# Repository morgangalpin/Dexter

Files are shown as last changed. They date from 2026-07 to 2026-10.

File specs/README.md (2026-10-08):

# Dexter — Specification

This directory is the **specification of the Dexter robot arm**: the authoritative design of
record from which all hardware, firmware, gateware, documentation, and build artifacts are derived.
It describes the robot — what it is, what it must do, and how it is built — not the process by which
this information was recovered. Where a design decision has been made, the specification states it as
the design; where a decision is still required to complete the robot, the specification records it as
work remaining (see [Design status](#design-status) and
[009-Design-Completion.md](009-Design-Completion.md)).

## Design identity and versioning

**No document in this set states its own version and revision**
([010 § Design identity](010-Versioning.md#2-design-identity)). The version line, the branch and tag scheme,
and the procedure for deriving the next revision are [010-Versioning.md](010-Versioning.md); the forward
roadmap is [011-Roadmap.md](011-Roadmap.md); the recorded history of each revision is
[CHANGES.md](../CHANGES.md) in the repository root.

## Specification map

Read top to bottom for a full picture; each document is self-contained and cross-links the others.

| # | Document | Scope |
|---|---|---|
| — | [README.md](README.md) | This map, document ownership, the design-status scheme, and the specs workflow |
| 001 | [Overview](001-Overview.md) | What Dexter is; system decomposition; how the specification is organized |
| 002 | [Requirements](002-Requirements.md) | Capabilities the robot must deliver: degrees of freedom, workspace, precision, motion limits, environment, interfaces |
| 003 | [Kinematics](003-Kinematics.md) | Coordinate frames, joint conventions, link lengths, the Denavit–Hartenberg model, and motion commands |
| 004 | [Mechanical Architecture](004-Mechanical-Architecture.md) | Joint-by-joint mechanical design: drivetrains, structure, and the design intent behind each subassembly |
| 005 | [Electronics and Control](005-Electronics-and-Control.md) | Sensing, actuation, the FPGA joint-servo loop, boards, power, and the control-command interface |
| 006 | [Firmware and Calibration](006-Firmware-and-Calibration.md) | Firmware parameters, the calibration model, and the factory calibration and bring-up procedure |
| 007 | [Bill of Materials](007-Bill-of-Materials.md) | The parts that realize the design in 004–006, organized by subassembly |
| 007.1 | [Parts Catalog and Sourcing](007.1-Parts-Catalog.md) | Every purchased and fabricated part, de-duplicated across the whole robot, with product specifications and supplier links |
| 007.2 | [3D Printed Parts](007.2-Printed-Parts.md) | Every printed part, de-duplicated, with print quantities and model-file sources |
| 008 | [Assembly](008-Assembly.md) | The procedure that builds the parts in 007 into the robot in 004 |
| 009 | [Design Completion](009-Design-Completion.md) | Design status: the open design decisions that must be closed to make the current design fully buildable |
| 009.1 | [Performance Characterization Protocol](009.1-Performance-Characterization-Protocol.md) | The first-build measurement protocol behind DC-9: test-by-test procedure, required instruments, and the recording template |
| 009.2 | [Test Build Manifest](009.2-Test-Build-Manifest.md) | What the first measurable build contains, the stages it is assembled in, and which open item each stage answers |
| 009.3 | [Render Program](009.3-Render-Program.md) | The single program that renders and verifies the printed-part meshes: its command line, the per-group `render.json` schema, and the parallel scheduling rules |
| 010 | [Versioning](010-Versioning.md) | Version lineage, design identity, the git branch and tag model for versions and revisions, and the procedure for deriving the next one |
| 011 | [Roadmap](011-Roadmap.md) | Improvements anticipated beyond the current revision |
| — | [CHANGES.md](../CHANGES.md) | The design history: what changed in each revision and why (repository root) |

Documents 002–005 specify the robot (requirements → kinematics → mechanics → electronics/control).
Documents 006–008 are **derived artifacts**: firmware configuration, the parts list, and the build
procedure all follow from the design in 002–005 and must be regenerated when it changes. 007.1 and 007.2
are derived one step further — from 007 — and each carries its own regeneration procedure. Document 009
is the live list of decisions still owed on the current revision; document 010 governs how the whole set evolves,
and 011 is what is intended beyond the current revision.

## Document ownership

Each document is the **single source of truth** for one set of information. Where another document needs
that information it links to the owner rather than restating it: a value written down twice will eventually
disagree with itself, and there is then no way to tell which copy is the design. When adding to the
specification, find the owner below and write it there.

| Information | Owner |
|---|---|
| What the robot must do: requirement IDs, targets, and their traceability | [002](002-Requirements.md) |
| Frames, joint conventions, link lengths, the DH model, and motion commands | [003](003-Kinematics.md) |
| Mechanical design and design intent, subassembly by subassembly; drive ratios and mechanical interfaces | [004](004-Mechanical-Architecture.md) |
| Sensing, actuation, boards, power, the control loop, and the command interface | [005](005-Electronics-and-Control.md) |
| Firmware parameter values, drive constants, and the calibration and bring-up procedure | [006](006-Firmware-and-Calibration.md) |
| Which parts each subassembly consumes, and in what quantity | [007](007-Bill-of-Materials.md) |
| Part identity, specification, supplier, price, and lead time | [007.1](007.1-Parts-Catalog.md) |
| Print quantities and model-file sources for printed parts | [007.2](007.2-Printed-Parts.md) |
| The order of operations that builds the robot | [008](008-Assembly.md) |
| **Design status** — what is still open, its priority, and its definition of done | [009](009-Design-Completion.md) |
| How a first build is measured, and what each measurement closes | [009.1](009.1-Performance-Characterization-Protocol.md) |
| The mesh render and verification program: command line, `render.json` schema, and scheduling rules | [009.3](009.3-Render-Program.md) |
| Version and revision identity, and the procedure for deriving the next one | [010](010-Versioning.md) |
| Work anticipated beyond the current revision | [011](011-Roadmap.md) |
| What changed in each revision, and why | [CHANGES.md](../CHANGES.md) |

Part geometry is owned by the model sources rather than by this set: a dimension a `.scad` file computes is
stated there, and referenced here.

**[`check-specs.rs`](check-specs.rs) enforces this.** It fails when a run of prose is restated across two
documents, when a document outside 009 labels its own design status, and when a cross-document link or
heading anchor does not resolve. Run it from the repository root before committing a change to the
specification:

```
./specs/check-specs.rs
```

An overlap that is genuinely not a second source of truth — a shared part number, a stock sentence opener
— goes in `specs/.duplication-allow` with a phrase from it. Suppressing a finding is a decision to be
made deliberately and rarely; the first question is always which document owns the information.

## Design status

Status is design maturity, and — like every other kind of information here — it has exactly one owner:
[009-Design-Completion.md](009-Design-Completion.md). **Every other document states the design as the
design of record and does not label its own maturity.** Where a passage depends on something still open, it
links to the item in 009 that owns it instead of repeating that item's state.

So read the set this way: **anything not named in 009 is `[Specified]`** — defined and traceable to
validated evidence (a physical unit, factory calibration data, released firmware, or a CAD model), and safe
to build to. What 009 lists is what is not yet that:

- **`[Provisional]`** — The design is defined by this specification and is the current design of record,
  but has not yet been validated on a physical build. It may change once verified. Treat it as a
  first-issue engineering design: buildable, but confirm before committing irreversible work
  (cutting carbon fiber, ordering long-lead parts).
- **`[TBD]`** — A design decision required to complete the current design has not yet been made. `[TBD]`
  items block a complete build.

The markers describe the **maturity of the design**, not the confidence of an observer. Each item cites its
**source of record** (a file, CAD assembly, factory document, or measurement) so the design remains
traceable. Provenance is traceability metadata, not the organizing narrative of the specification.

---

# Specs Directory (workflow)

Specification files are the source of truth. All code, documentation, and artifacts are derived from specs.
Project specification files are contained in the `specs/` directory in the project root.
Finer-grained feature spec files are contained in a `specs/` directory in a feature's subdirectory.

## File Naming
- `<number>-<descriptive-name>.md` where number is a 3-digit prefix (001, 002) and name is kebab-case.
- Use decimal notation for related specs (001-Overview.md, 001.1-Architecture.md, 001.2-Stack.md).

## Workflow
1. Find the owning document ([Document ownership](#document-ownership)) and update it there.
2. Generate/update code, tests, documentation, and build artifacts from the spec.
3. Verify the artifacts match the spec and that tests validate the requirements.
4. Run `./specs/check-specs.rs` and resolve anything it reports.

For this hardware project the "artifacts" derived from the spec are the firmware configuration
([006](006-Firmware-and-Calibration.md)), the bill of materials ([007](007-Bill-of-Materials.md)), the
assembly procedure ([008](008-Assembly.md)), and the CAD/build files they reference — not application code.
When the design in 002–005 changes, regenerate those derived documents to match.

## Diagrams
- Use Mermaid for all diagrams.
- May be inlined as mermaid code blocks.

## Documentation Standards
- Update spec files during design and build with details, clarifications, and behavioral requirements discovered.
- Record architectural decisions in `specs/*.md` for consistency across revisions.
- Correct grammar and punctuation are required in all documentation and comments.
- Use neutral statements describing the robot ("The base is bolted to a rigid surface"), not the author's process.

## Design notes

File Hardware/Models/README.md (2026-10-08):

# Models

Model files for the robot's printed parts, organized by **arm component**. This directory is the build
source: everything needed to print one complete robot is here, and nothing else is. Most parts are meshes
you can print directly; `700-Differential/` is parametric `.scad` and is rendered first, as is the base
mounting plate — see [Moving to OpenSCAD](#moving-to-openscad).

- **[robot_assembly.scad](robot_assembly.scad)** — the arm composed in the CAD kinematic frame, so the
  build can be reviewed by looking at it. Every placement in it is solved from a feature the part carries;
  a part whose position nothing fixes is listed in that file's `UNPLACED` rather than drawn somewhere
  plausible, which is what lets a missing part show as a hole. `700-Differential/diff_assembly.scad` is the
  same idea one level down, and this file composes it in by its `diff_centre()`. A mating feature outranks
  a bounding box there: the differential is oriented by the L3 spigot Diff Body A carries and by the side
  its End Pulley faces, and where the measured cover bodies disagree with that the file reports the
  disagreement rather than moving the part into them.
- **[print_fit.scad](print_fit.scad)** — the two print-fit clearances every part's `config="revised"`
  draws its fits with, press and slip, and the running gap kept between parts that turn past each
  other. Tune the two fits on
  [`950-Tooling/fit_coupon.scad`](950-Tooling/fit_coupon.scad); the policy is
  [007.2 § Print fits](../../specs/007.2-Printed-Parts.md#print-fits).
- **[PART-INDEX.md](PART-INDEX.md)** — every part in
  [007.2](../../specs/007.2-Printed-Parts.md#printed-parts) with its file, grouped as the directories are.
- **[MANIFEST.csv](MANIFEST.csv)** — every model and model-source file (meshes, CAD, `.scad`, and the
  script that renders and verifies them) with its size, SHA-256, and, for STLs, format and triangle count.
  Sizes and hashes are of the **repository** bytes, so text files are counted with LF line endings — on a
  Windows checkout (`core.autocrlf=true`) the working-tree file is larger than its row says. Compare a
  text file by normalizing CRLF to LF first; binary files compare directly. The text set is `.step`
  (ISO-10303-21 is ASCII), `.scad`, `.rs`, `.json` and `.md`; `.stl`, `.f3d`, `.ipt`, `.dwg`, `.skp`
  and `.skb` compare directly. The group column is the file's directory; a file that belongs to no one
  component group is grouped `(all)`.

## Layout

Directories follow the `PBS` component groups in [007.2](../../specs/007.2-Printed-Parts.md#printed-parts).
Files are named `<PBS>_<PartName>.<ext>`, so a part number alone locates its file, and the directory
listing sorts in build order.

`PBS #` is the **authoritative part number** — the only scheme that names every part, and the one
[007](../../specs/007-Bill-of-Materials.md), [007.1](../../specs/007.1-Parts-Catalog.md),
[007.2](../../specs/007.2-Printed-Parts.md) and [008](../../specs/008-Assembly.md) all key on. The `HDI-`
and `TI1-` CAD IDs name bodies in the CAD model and cover only 13 of 70 parts; the `KP`/`KA` numbers in
[`Reference/onshape-v1/`](Reference/onshape-v1/README.md) belong to the superseded v1 design. See
[007.2 § Part identifiers](../../specs/007.2-Printed-Parts.md#part-identifiers).

| Directory | Parts | Files | What |
|---|---|---|---|
| [`100-Base/`](100-Base/) | 7 | 9 | Base clamp, mount, mounting plate, stator holder, code disc; the Stator Holder is `.scad` |
| [`200-ArmBody/`](200-ArmBody/) | 9 | 9 | Arm body, stator holder and balancers, belt directors; the Stator Holder is `.scad` |
| [`300-Pivot/`](300-Pivot/) | 4 | 4 | Main pivot, code disk, motor end caps |
| [`400-EndArm/`](400-EndArm/) | 10 | 12 | Axis intersection, hub, internal and external pulleys; the External pulleys are `.scad` |
| [`500-ExternalGear/`](500-ExternalGear/) | 7 | 9 | External gear, stator holder, mount and nut holders; the Motor End Cap and Stator Holder are `.scad`; `exgear_assembly.scad` places the group with its motor and drive, and closes J3's stack |
| [`600-StrainWave/`](600-StrainWave/) | 3 | 5 | Wave gen coupler, flex spline attach and cap; the Attach and Cap are `.scad`, and `c201_spline_seat.scad` holds the drive's interface for them and the three Stator Holders |
| [`700-Differential/`](700-Differential/) | 10 | 17 | Split gears, diff gear shaft and axle, diff pulleys, diff bodies — **the OpenSCAD set**, `.scad` only; the meshes it is measured against are under `Reference/meshes/`; `diff_assembly.scad` places the set and has a section view |
| [`800-Harness/`](800-Harness/) | 14 | 17 | Wire entries, pivot plugs, PCB brackets, strain reliefs, photointerrupter shrouds |
| [`900-ToolInterface/`](900-ToolInterface/) | 8 | 27 | Tool interface body, roll, span, gripper — **the parametric set** |
| [`950-Tooling/`](950-Tooling/) | 2 | 12 | Solder jigs, glue-rig jig bodies, and the print-fit coupon |
| [`Reference/`](#reference) | — | 226 | Not printed for a build. See below |

### Shared parts

Sharing happens at **subassembly** level, not file level, so no part lives in two directories:

- **`600-StrainWave/`** is three parts at quantity 3 — one adapter set per strain-wave joint (base, pivot,
  end arm). It is a component in its own right rather than a member of any one joint.
- **`800-Harness/`** parts are distributed throughout the robot (strain reliefs at quantity 10, PCB spacers
  at 4).

Only two *files* serve more than one part number, and both stay inside one component. See
[PART-INDEX](PART-INDEX.md#one-geometry-two-part-numbers).

### Reference

Not part of a build. Kept because the geometry exists nowhere else.

| Directory | Files | What |
|---|---|---|
| `Reference/onshape-v1/` | 193 | **v1** B-rep solids as STEP, plus assembly definitions. Dimension recovery only — see [its README](Reference/onshape-v1/README.md) |
| `Reference/inventor/` | 8 | Inventor `.ipt` with feature history: arm, CF tube and tube mould, valve and ratchet, arm-body spacer. No part in the build list maps to these |
| `Reference/covers/` | 6 | Cosmetic ducts, **not in the [007](../../specs/007-Bill-of-Materials.md) build list**. Includes SketchUp source |
| [`Reference/meshes/`](Reference/meshes/) | 17 | The original meshes of parts that now have parametric source: `700-Differential/`, `400-EndArm/`'s two External pulleys, `500-ExternalGear/`'s Motor End Cap, `600-StrainWave/`'s Flex Spline Attach and Cap, and the three Stator Holders in `100-Base/`, `200-ArmBody/` and `500-ExternalGear/`. A part's mesh moves here when its `.scad` lands; `render.rs --verify` measures its renders against these meshes (see [Checking a group](#checking-a-group)), and each External pulley `.scad` builds on its own |
| [`Reference/superseded/`](Reference/superseded/) | 2 | Earlier revisions of parts the build no longer uses. `GlueRig_EndArmHubToDiff_B_span309500.stl` is the L3 rig as first exported ([PART-INDEX](PART-INDEX.md#glue-rig-jigs)). `DiffA2CodeDiskEndStop.dwg` is the v1 J4 code disk and end stop, whose 115-slot track is now cut into `#730-002`'s rim |

## Known defects

**A tangency, corrected in place.** `400-EndArm/420-001_EndArmHub.stl` was not a closed 2-manifold. The
part carries four Ø3.000 holes whose centres sit on a Ø30.500 circle, each tangent to the Ø27.500 bore
exactly — 15.250 − 1.500 = 13.750 — and the tessellator honoured the tangency by giving both surfaces a
vertex at the same coordinate. At three of the four, (0, 13.750), (0, −13.750) and (13.750, 0) in the
part's own frame, they then shared the whole line from z = −2.000 to z = −30.000: four faces on one edge
instead of two, and two cones of faces meeting at the single vertex at the z = −2.000 end, with no way to
say which faces bound the material. The fourth, at (−13.750, 0), is cut into different segments on each
surface, shares no edge, and is manifold — which is why there were three and not four. CGAL takes none of
it, so a render of anything holding this part stopped at `The given mesh is not closed`.

It was not a hole — the mesh has no boundary loop anywhere, which is why `scadmesh repair` reported it as
not closed and then found nothing to fill — so what it needed was each contact opened rather than patched:

```
scadmesh pinch 400-EndArm/420-001_EndArmHub.stl --out 400-EndArm/420-001_EndArmHub.stl
```

That gives one surface at each contact its own vertex 1 µm off the line, along its own normal, which grows
the material between the two surfaces by that much: 6 triangles added, no existing vertex moved, the
bounding box unchanged and the volume 0.028 mm³ — four parts in ten million — larger. The file also holds
a second closed shell that shares no edge with the body, the 18 × 20 × 20 mm block on the spigot axis at
x 26.500..44.500, y ±10.000, z −35.000..−15.000, so this is a multi-body export rather than one unioned
solid. That is not a defect: two shells convert as readily as one.

**A second tangency, corrected the same way.** `500-ExternalGear/510-001_ExternalGear.stl` failed the same
way. Two of its surfaces shared 91 edges on one ring in the part's frame, at x 21.215 and r ≈ 33.7, so
`scadmesh repair` found no boundary loop, CGAL refused the mesh, and every boolean on the gear stopped at
`The given mesh is not closed`. It is corrected in place:

```
scadmesh pinch 500-ExternalGear/510-001_ExternalGear.stl --out 500-ExternalGear/510-001_ExternalGear.stl
```

That added 182 triangles, left the bounding box unchanged, and added 0.708 mm³ to the volume (1 part in
10⁵). The gear now intersects with the Mount, the Mount Top and the lower 6810. Two pairs still fail
inside CGAL's boolean (`applyBinaryOperator` asserts) and stay unjudged. The Stator Holder's keys meet
the gear's slots line-to-line, which is why `render.rs --verify` checks that fit by sections.
The upper 6810's assertion persists with its envelope shrunk to Ø64.9, so it is not the seat's Ø65; its
cause is not isolated.

Three files have held the wrong geometry rather than the wrong topology, and all three are corrected in
place:

- `100-Base/110-001_BaseMountBottom.stl` was the **un-bolted predecessor**, an 85 × 85 × 98 mm part whose
  bottom face carried no fastener features whatever: sections through it return only an outer Ø ≈ 72.9
  profile and a Ø53.99 bore, and the six 60°-spaced features on its Ø71.302 circle decompose into six
  straight lines — 12.94 × 3.82 mm slots for the `#110-003` CF strakes, not a bolt pattern. The design of
  record is a **bolted** base ([004 § Base (J1)](../../specs/004-Mechanical-Architecture.md#base-j1)), and
  the CAD model holds it as `BaseMountBottom_Bolted v9`: 150 × 150 × 98 mm, with eight Ø6.000 mounting
  holes through a 10 mm flange. That is now the file, exported from `dde/HDIMeterModel.gltf` in the part's
  own frame. **This was found by re-checking a file the manifest was perfectly happy with** — the previous
  entry was a valid, closed, correctly named mesh of the wrong revision.
- `200-ArmBody/200-001_ArmBody.stl` was not the Arm Body. It held
  `ArmBodyFrontStrakeMED.stl` — a 20-triangle 4.9 × 9.9 × 32 mm block — byte for byte, so the mirror
  had matched the archive's `ArmBody*` prefix rather than the part. The Arm Body is
  `ArmBodyWEncode.stl` in [thing:3781990](https://www.thingiverse.com/thing:3781990) (11,946 triangles,
  99.6 × 108.1 × 98.0 mm), and that is now the file. It is the part: its 29 × 29 mm L2 tube socket sits
  where the CAD model's `HDI-310-001_ArmBody` puts it, to the seat depth
  [C-504](../../specs/007.1-Parts-Catalog.md#c-504--braided-carbon-fibre-square-tube-1) states. **Any prefix-matched file in
  this mirror is worth re-checking the same way** — a file that is the right size and the wrong part
  passes every check the manifest makes.
- `Reference/meshes/700-Differential/710-002_SplitGearBottom.stl` was 1000× out of scale; it is
  dimension-checked against its mates and now also has parametric source
  ([DC-11(f)](../../specs/009-Design-Completion.md#procurement-data)).

The Base Mount Bottom is the only file here taken from the GLTF, and it takes two steps rather than one:

```
scadmesh gltf dde/HDIMeterModel.gltf --node HDI-110-001_BaseMountBottom \
    --frame HDI-110-001_BaseMountBottom --scale 1000 --out raw.stl
scadmesh repair raw.stl --out 100-Base/110-001_BaseMountBottom.stl
```

`--scale 1000` is needed because `--frame` reports the node's own units — metres here — where the default
world export converts to millimetres. And the GLTF mesh arrives with three 11.5 µm holes at the central
bore's seam, so it is not a closed solid until `repair` triangulates them; every other mesh in this
directory is closed, and this one now is too. The repair adds 3 triangles and moves no existing vertex,
leaving surface area and enclosed volume unchanged.

`Reference/meshes/700-Differential/720-002_DiffGearAxle.stl` is the set's only ASCII STL. That is not a
defect — it prints normally — but it is why [MANIFEST.csv](MANIFEST.csv) records it as `ascii-or-nonstd`
with no triangle count.

## Formats, and what can actually be edited

| Format | Where | Editable? |
|---|---|---|
| `.scad` | `700-Differential/` | **Yes** — parametric OpenSCAD source, the intended format going forward (see below) |
| `.stl` | component directories, `Reference/meshes/` | **No.** Mesh only — printable, not meaningfully modifiable |
| `.f3d` | `900-ToolInterface/` | **Yes** — Fusion 360 native, with feature history |
| `.step` | `900-ToolInterface/`, `Reference/onshape-v1/` | **Partly** — B-rep solids. Dimensions can be measured and features cut, but there is no feature tree to drive |
| `.ipt` | `Reference/inventor/` | **Yes** — Inventor native, with feature history |
| `.dwg` | `400-EndArm/`, `900-ToolInterface/`, `Reference/superseded/` | **Partly** — B-rep solids, not 2D profiles as previously recorded here. Each of the three holds one ACIS `3DSOLID` (`421-002` adds six lines and an arc beside it). Reading one needs the [ODA File Converter](https://www.opendesign.com/guestfiles/oda_file_converter); FreeCAD drives it once its path is set, and `ODAFileConverter in/ out/ ACAD2000 DXF 0 1 "*.dwg"` writes the solid as ASCII-encoded SAT in the DXF's group 1 and 3 records |
| `.skp`/`.skb` | `Reference/covers/` | **Yes** — SketchUp source |

**Most of the robot is still mesh-only.** Editable source exists for the differential (`.scad`), the tool
interface (`.f3d`), and the Inventor reference parts. Everything else is a mesh or a dead solid, so
changing one of those parts today means re-deriving it from an STL — the workflow the differential
conversion established (see below). That remaining gap is tracked as
[DC-11](../../specs/009-Design-Completion.md#procurement-data).

## Moving to OpenSCAD

`.scad` is the intended parametric format going forward: it is text, so it diffs and merges in Git, and it
depends on no proprietary tool. Four conventions keep the transition legible:

- **Share the stem.** A rewritten part keeps its mesh's name — `100-001_BaseClamp.scad` for
  `100-001_BaseClamp.stl` — so the two stay findable from each other after they are separated.
- **Treat the STL as output, not source, once a `.scad` exists.** Until then the STL *is* the source of
  record, because for most parts it is the only geometry that exists.
- **Move the mesh to `Reference/meshes/<group>/` when the group is converted**, keeping its stem and
  group directory. It stops being the build source at that point and becomes only what the render is
  gated against, and leaving it in the component directory invites printing the mesh instead of the
  `.scad`. A **converted** part therefore has no `.stl` beside its `.scad`, and which groups have been
  converted is visible from a listing of `Reference/meshes/`. The rule is about a part, not a directory:
  `100-Base/` holds `110-004_BaseMountingPlate.scad` beside six meshes because that part was *authored*
  rather than converted, and the meshes belong to parts nothing has rewritten yet. What a directory must
  never hold is a `.scad` and an `.stl` of the **same** part.
- **Wrap a nested `difference()` in `render()`, not the cut that follows it.** OpenSCAD's *preview*
  normalizes the tree to disjunctive normal form, and `x - (A - B)` rewrites to `(x - A) | (x & B)` —
  one copy of the entire part per term of `A` and of `B`. A subtracted union does not multiply, so an
  array of cuts is rarely the cause even when it is what overflows: it is the nested difference upstream
  that multiplies, and the array merely lands on every copy. Two symptoms follow, and the second is the
  one that gets misread. Past the element cap the normalizer gives up and preview draws an empty tree,
  so a part can export a flawless STL and show nothing. Below the cap it draws, but every primitive is
  redrawn once per product per frame, and the viewport stops turning. `render()` on the nested
  difference collapses it to one mesh, removing the fan-out at its source and costing the export
  nothing. Take the deepest multiplier first: wrapping a downstream cut while a large factor survives
  upstream caps the element count without touching the product count, which cures the empty tree and
  leaves the model exactly as unusable to turn.
  [`730-002_DiffBodyB.scad`](700-Differential/730-002_DiffBodyB.scad) is the worked example — its Ø8
  bore fillet multiplies the whole part, its 115 encoder slots merely land on every copy — and the
  arithmetic and measurements are at that call site. Two things there carry elsewhere. The cheaper
  lever is often not `render()` at all: that fillet's factor is set by how its cutter is built, and
  rebuilding the cutter as a swept polyhedron rather than a chain of hulled spheres took it from 51 to
  7 for nothing. And **measure compile and frame separately** — render the same file at two image
  sizes, because compile does not scale with pixels and a frame does. On that part the variant that
  compiled fastest was the one that could not be orbited, and reading the two costs as a single number
  is what hid it.

**`700-Differential/` is fully converted** (DC-2,
[specs/009](../../specs/009-Design-Completion.md#differential-detail-design)): one `.scad` per part,
shared dimensions in `diff_params.scad`, placements in `diff_assembly.scad`, and `render.json` for `render.rs` to render
both configurations and dimensionally verify each render against its reference STL with `scadmesh`
(from the standalone `openscad-tools` project, checked out beside this repository's parent — bounding
boxes, diameter and face-position bands, cross-sections, tooth counts). Use that directory as the template
for converting the remaining groups.

**Printing the differential therefore takes one command first**: `./render.rs 700-Differential --meshes` writes the
ten meshes to print into `700-Differential/out/revised/`. `out/` is deliberately untracked — a rendered mesh is a build
artifact, and tracking it would leave two copies of the same geometry to disagree. Everything the render
is checked against is under
[`Reference/meshes/700-Differential/`](Reference/meshes/700-Differential/).

`Reference/onshape-v1/parts-step/` is the most useful starting material: STEP solids can be measured for
real dimensions, which an STL cannot give you reliably.

### Verifying a recreated part against its reference

A recreated part is gated on **surface distance**, not on dimensions. `scadmesh compare` asks whether
every reference diameter and face position reappears somewhere in the candidate — a set of
one-dimensional histograms that a wrong body can satisfy in full: a missing boss, a square hole where the
reference has a round one, and a dished flank where the reference bulges all leave the histograms intact.
It once reported ±0.006–0.131 mm agreement on parts deviating by up to 3.8 mm. **A dimensional check is
not a shape check**, and no tightening of its tolerance makes it one. `compare` is retained only to name
*which* dimension moved once `dist` has failed a part; it gates nothing.

The contract every part in `700-Differential/` is held to:

- **`scadmesh dist` within ±0.15 mm in both directions.** Both are required, not a formality:
  candidate→reference finds material the model invented, reference→candidate finds material it never
  reproduced, and a model that is a strict subset of its reference passes the first alone.
- **Build the body from its measured meridional profile** (`scadmesh profile`) rather than from inferred
  diameters and face heights, so flank curvature is reproduced instead of guessed.
- **Preview (F5) as well as render (F6)**, checked rather than assumed — preview fails independently of
  rendering, so exporting an STL and measuring it will pass a part that shows nothing in the GUI. Run
  `openscad --preview -o check.png <part>.scad` and require zero warnings. The failure mode is specific:
  **no cutter may be a module that is internally boolean** — BOSL2's `pie_slice()` and anything taking
  `rounding=`/`chamfer=` are — because `A - (B - C)` normalizes to `(A - B) | (A & C)` and each one
  doubles the preview tree. Build cutters from single primitives, and cut each solid before unioning it
  into an array rather than after.
- **A shared face is not a join.** Where a feature is trimmed to the surface of the blank it stands on,
  CGAL returns the two as separate solids, the blank's face survives the union underneath the feature,
  and the export carries interior surface — which `dist` then measures against nothing, reading over a
  millimetre out on geometry that is dimensionally correct. Trim such a feature to a surface **offset
  into** the blank (`BEVEL_ROOT_UNDER` offsets 0.35 mm) and let the overlap be buried. The `Volumes:`
  line of the render log is the cheap check: a part modelled as one solid must report 2.

**The references are CAD assembly exports (`STLB ASM` headers) and they mislead in three ways.** Run
`scadmesh segment` on a reference before measuring it.

- *Zero-thickness internal shells.* `profile` shows these as doubled-back slivers, one measuring
  0.003 mm across in `710-002`. A clean model must not reproduce them.
- *Unmerged solids.* `710-002` is two bodies — a turned body and a tooth crown, tessellated at 3.85 and
  6.91 triangles/mm² and never merged. Its file volume **double-counts** the ≈352 mm³ where they
  interpenetrate, so a faithful model reads 4.8 % light against the file and correct against the merged
  7001 mm³; volume against an unmerged file is a screening signal, not a verdict. And reference→candidate
  `dist` flags every **buried** surface, because a merged model has no counterpart for them — on this
  part 28 % of reference samples at up to 2.25 mm, none of it a defect. Only candidate→reference gates a
  part whose reference is an assembly export.
- *Stray shells.* `730-002`'s export carries six 1.05 × 1.0 × 1.0 inverted shells (−0.815 mm³ apiece)
  beside the body, and `dist` against the whole file scores them at **0.991 mm**. Against the isolated
  body the same comparison reads **0.332 mm**. Every figure quoted for that part is against body 0, and a
  measurement that skips `segment` reads a part three times worse than it is.

Not every oddity in a reference is an artifact. `720-001`'s apparent degenerate Ø15.5 internal shell is
**twelve Ø0.2 through-holes** on a Ø15.5 circle, 30° apart with one on +x, running the full 60.6 mm of the
part: every triangle around a hole has its normal on that hole's own axis, `segment` returns one closed
body, and the lateral area over any span is π·0.2·span to three decimals. The model reproduces them behind
a `wall_holes` flag. They are **not buildable** — Ø0.2 × 60.6 mm is 303:1, past drilling and far past
printing — so the flag defaults off and the built shaft is solid
([007.2](../../specs/007.2-Printed-Parts.md#differential--0076)).

Two exceptions are enumerated explicitly rather than absorbed into a widened tolerance. The **GT2 pulley**
teeth are cut with a modelled groove profile rather than measured. The **Diff Gear Shaft's tooth form** is
deliberately cut to the shared crown rather than to its own superseded reference
([CR-3A7](../../CHANGES.md)), so its `dist` fails ±0.15 mm in the tooth zone by design; its tooth count
(20, exact), its clocking (within 0.3° of the reference) and every dimension outside the tooth zone are
gated as usual, measured on the render itself. There is **no tooth-band exemption for the bevels** — the
crown is measured (`diff_bevel.scad`) and meets the ordinary surface check with room to spare.

### Checking a group

Every group with `.scad` parts carries a `render.json`, and `./render.rs <group> --verify` (run from this
directory; `all` takes every group) checks it. It renders the group's parts into the group's untracked
`out/`, gates each faithful render against its mesh under `Reference/meshes/<group>/` by the contract above,
checks the revised geometry by probing material and void either side of the faces it moved, and ends in
`ALL CHECKS PASSED` or a failure count. The work runs in parallel; the schema, the check kinds and the
scheduling rules are owned by [`specs/009.3-Render-Program.md`](../../specs/009.3-Render-Program.md).

The machinery is shared, not copied: the [`render-check/`](render-check/) crate, which `render.rs` takes
as a path dependency, finds OpenSCAD and `scadmesh` (`$OPENSCAD` and `$SCADMESH` first), runs a render and
fails it on any warning, a result CGAL reports as not simple, or an empty one, runs the `dist` gate, probes points, and reads
echoes. A group's `render.json` holds only its own gates and checks. Three rules keep the groups from drifting apart:

- **A number a check needs comes from the part.** A `.scad` echoes it at top level as
  `echo(name = value)`, and the check reads that line; the value is never retyped into `render.json`.
- **A group that uses another group's part waits on that group's jobs** rather than repeating its gates.
  `500-ExternalGear/render.json` waits on `600-StrainWave/*` for face-630-005-j3, because J3's stack
  depends on the Flex Spline Attach.
- **A group states its parts once**, in the `parts` of its `render.json`.
  `render.rs --meshes` builds the mesh cache from the same list the checks verify, so an edited part
  reaches the assembly view and the gates alike.
- **`render.rs` is cached by rust-script.** An edit to `render-check/` does not rebuild it. After changing
  the crate, run `rust-script --force render.rs ...` once, then `rust-script render.rs ...`; running
  `./render.rs` directly can use an older build. `700-Differential --verify` takes about 34 minutes.

Two checks are shared across groups. The `seat` kind probes a Stator Holder's revised seat against C-201's
hole pattern as [007.1](../../specs/007.1-Parts-Catalog.md#c-201--521-strain-wave-component-set) states
it, rather than as the seat library cuts it, so the probes test the library. The `clash` kind renders an
assembly's pair. It passes when the intersection is empty or has no volume (a seat, where two
parts share a face), and fails when CGAL cannot intersect the pair at all, because a failed boolean
returns one of its operands.

### Measured state of the differential set

`scadmesh dist`, two-sided sampled surface distance against each reference, in mm. All nine parts render
as one clean solid from measured geometry.

| Part | Worst deviation | Volume vs reference | State |
|---|---|---|---|
| 710-001 Split Gear Top | 0.045 | −0.1 % | faithful (p95 0.010) |
| 710-002 Split Gear Bottom | 0.150 | +0.02 % | faithful (p95 0.050) |
| 710-003 Diff Keeper | 0.023 | −0.8 % | faithful |
| 710-004 Rotate Code Disk | 0.350 | −1.4 % | faithful (p95 0.011; one localized edge) |
| 720-001 Diff Gear Shaft | 0.568 / 0.456 | −2.05 % | cut to the shared crown — fails ±0.15 mm by design |
| 720-002 Diff Gear Axle | 0.094 | −0.02 % | faithful (p95 0.028) |
| 720-003 Diff End Pulley | 0.030 | −0.02 % | faithful |
| 730-001 Diff Body A | 0.016 | — | faithful, 0.000 % of samples over tolerance |
| 730-002 Diff Body B | 0.377 / 0.332 | −0.05 % | **not yet gated** — see below |

`710-002`'s 0.150 mm is a defect in the reference, not the model: circle fits at z 6.3–6.9 centre the
Ø8.5 bore and its funnel on (−0.039, 0.138), **0.143 mm off the axis**, while every turned surface around
them fits the axis to 0.001 mm. It is a clearance hole for wire, so the model keeps it concentric, and
that eccentricity is the whole of the part's excursion past tolerance (0.011 % of samples).

`730-002` is absent from `DIST_GATES`. p95 is inside tolerance in both directions (0.136); it is the
maxima that fail, and both are the same feature on opposite y flats — the chimney base's straight sides
meeting the chimney cone, filleted on the reference at radius ≈1.5 and modelled here as sharp
intersections, 0.377 mm at (32.686, −9.406, 31.057) and 0.332 mm at (32.346, −32.469, 30.915). Filleting
those four junctions is the remaining work, tracked as
[DC-2](../../specs/009-Design-Completion.md#differential-detail-design). Its measured geometry — the
profiles are the dimension tables — is recorded in
[`730-002_DiffBodyB.scad`](700-Differential/730-002_DiffBodyB.scad).

### What the rebuild established

Four findings generalise beyond the differential and are worth applying to the remaining groups.

- **Revolved bodies recover as cones.** Every crown surface on `710-001`, `710-002` and `720-002` is a
  cone, and fitting measured radius against height recovers each one exactly — the four fitted on
  `720-002` leave a maximum residual of 0.0003 mm over six heights. Cone intersections then define every
  edge outright, so no corner coordinate is measured twice.
- **Straight bevel teeth are ruled through the gear apex**, so *one* section reproduces the whole tooth:
  scaling it about the axis by the ratio of heights **is** the surface between them, which
  `linear_extrude(scale=)` draws exactly and without facets. Nothing needs a loft through stacked
  sections. Let the revolved envelope supply the tip, root and end faces, leaving the section responsible
  for the flanks alone. The apex is measured rather than assumed — scaling a section at one height onto a
  measured section at another and minimising the mismatch locates it to ±0.02 mm.
- **A bevel flank is a cubic.** Fitted to 253 measured points (the median over 9 heights × 20 teeth,
  which agree among themselves to 0.002 mm), a single cubic Bézier holds them to **0.006 mm max, 0.003
  RMS** — where the polyline it replaced needed several hundred coordinates per part and still rendered
  as visible facets. Rebuilding this way took `710-001` from 0.225 mm to 0.045 mm, made its bounding box
  exact, cut its triangle count by 56 %, and carried the tooth's concave root fillet as measured, which a
  loft through convex hulls cuts the corner across.
- **Author a shared feature once.** The Split Gear and the Diff Gear Axle are not two similar gears but
  one 20-tooth crown placed twice: sections taken 15.4484 mm apart return outlines **0.0001 mm apart over
  4088 points**, already clocked alike, and `710-002` supplies exactly the material inside the parting
  cone that `710-001` lacks — its area agreeing with `720-002`'s whole tooth ring to 0.007 mm² in 858.
  The gear is defined once in `diff_bevel.scad` and each part intersects it with its own envelope, so
  they cannot drift out of mesh in edit.

### What assembling the set showed

Per-part gating cannot see fit: a part can match its own reference to a hundredth of a millimetre and
still not fit its neighbours. `diff_assembly.scad` places every part by a feature it carries rather than
by a typed offset, and records each finding at the call site that exposes it.

- **The three bevels mesh**, checked rather than asserted: the CGAL intersection of the Split Gear
  against the Diff Gear Axle, and against the Diff Gear Shaft, is **empty in both cases** — as is the
  intersection of whole 20T crowns substituted for both side bevels, whose tips are longer than the
  shaft's cut ones and so is the stronger result. A bevel set meshes exactly when its apexes coincide,
  and each part states where its apex sits on its own axis, so placing the parts by those three numbers
  is the whole of the gear train.
- **The Split Gear's halves need no relative transform.** `710-001` and `710-002` are authored in the
  same frame, and their intersection is a set of open shells enclosing **exactly 0.000 mm³ apiece**
  (`scadmesh segment`), bounded by the seating face at z = 4.000 and by `BEVEL_SPLIT_ROOT` — both
  construction points rather than accidents. An earlier assembly mirrored one half against the other,
  which cannot be right: mirrored about the shared apex the two crowns do not overlap anywhere.
- **The brad holes disagreed by 0.5 mm.** `710-001`'s hole runs z 11.534–12.943 and `710-002`'s
  z 12.089–13.456 — about 1.0 mm of common opening for a Ø1.5 hole taking a Ø1.8 interference-fit brad.
  Neither half can move to fix it, so this is a disagreement between the two references. `config="previous"`
  keeps each reference's own value; `config="revised"` drills both at **z = 12.750**, stated once as
  `BRAD_Z` in `diff_params.scad`. That height is the one both parts have material for (it leaves a full
  millimetre of `710-002`'s Ø27 wall below the hole, where 12.250 would leave 0.500 mm) and it is the
  blind, glued half's own value — the hole that actually holds the brad. Verified by intersecting a
  Ø1.45 probe on that axis with both halves as they sit: **empty in `revised`, not empty in `previous`**.
  The assembly draws the four brads only when both halves drill to one line, so the previous config still
  shows the disagreement by leaving them out.
- **Four stack-ups are kept as measurements in `config="previous"`, and `config="revised"` designs them
  out.** The Diff Gear Axle's boss reaches into the shaft's front MR128 seat, and Diff Body B overlaps the
  toes of all three bevel crowns that turn in it. `revised` seats the boss on that bearing and keeps Body B
  the running clearance off each crown's swept teeth. The figures and constructions are in
  [`diff_assembly.scad`](700-Differential/diff_assembly.scad)'s header and `730-002`'s TOE CLEARANCE.

## Viewing an assembly

An assembly `.scad` can be turned into a section viewer page, an orthographic model cut on a movable
plane with its parts listed, grouped and labelled, by `scadmesh view` from `openscad-tools`. The
assembly must be **viewable**:

- A top-level `part` variable selects what it draws: `"all"`, or one part's id, drawn in its assembled
  position.
- Every value the page quotes is echoed at top level as `echo(name = value)`.

A sidecar `<assembly>.view.json` beside it names the parts, colours and groups, the labels and camera
presets, and the notes. It restates no dimension: part heights come from the exported meshes, and text
quotes echoes through `{name}` placeholders. The format is in `openscad-tools`'
`specs/003-CLI.md` § The view sidecar. Every `*.view.json` in this tree names a viewable assembly.

### Prerequisites

- **OpenSCAD**, found as `openscad-tools`' `specs/003-CLI.md` states for `view`.
- **`scadmesh`** on `PATH`, built from `openscad-tools` (its README § Build); `cargo install --path .`
  in that checkout installs it.
- **`miniserve`**: `cargo install miniserve`.

### Building, serving and opening a view

Run from the directory that holds the assembly — `500-ExternalGear/` for the External Gear stack:

```
scadmesh view exgear_assembly.view.json --out out/view
miniserve out/view
```

and `700-Differential/` for the wrist differential, whose assembly imports the mesh cache that
`render.rs --meshes` builds, so the cache is built first:

```
./render.rs 700-Differential --meshes
scadmesh view diff_assembly.view.json --out out/view
miniserve out/view
```

Then open `http://localhost:8080/index.html`.

- `scadmesh view` writes `out/view/index.html` and one `out/view/parts/<id>.json` per part. OpenSCAD
  exports each part in its own run, one after another, so the build takes the sum of the parts'
  renders — about eight minutes for the External Gear stack. The page is output, like any render, and
  `out/` is untracked.
- The page loads its parts over HTTP, so it must be served; opened from disk (`file://`) it draws no
  parts.
- A rebuild while `miniserve` runs needs only a browser refresh. `Ctrl+C` stops the server, and
  `miniserve -p <port> out/view` serves on another port when 8080 is taken.

### Making an assembly viewable

1. **Write the assembly.** A group's assembly is `<group>/<short>_assembly.scad`; the arm's is
   [`robot_assembly.scad`](robot_assembly.scad). Place every part by a feature it carries, as the
   arm's assembly does. Copy the viewable shape from
   [`exgear_assembly.scad`](500-ExternalGear/exgear_assembly.scad): the `part` variable, a `PARTS` list
   of ids, one module per part, a `draw(p)` that dispatches on the id, and an `assembly()` that draws
   every id `part` selects. Echo every value the page will quote.
2. **Check one part exports alone** — `openscad -D 'part="<id>"' -o check.stl <assembly>.scad` — with
   no warnings.
3. **Write the sidecar**, `<assembly>.view.json` beside the assembly, to the format above;
   [`exgear_assembly.view.json`](500-ExternalGear/exgear_assembly.view.json) is the worked example.
   Every part `id` is an entry of `PARTS`, and every number the page shows is a `{name}` placeholder
   for an echo, never typed.
4. **Build and open it** as above. `scadmesh view` rejects an unknown field, a duplicate id, or a
   label, preset, overlap or focus that names no part or preset before it exports anything, so a
   sidecar mistake fails in seconds.

## What was removed

This directory previously mirrored 909 files (571 MB) organized by where they were downloaded from. That
was reduced to the parts a build needs. Removed:

| Removed | Files | MB | Why |
|---|---|---|---|
| Dropbox in-work variants | 281 | 202.8 | Experimental sweeps (`SplitGearRIN5ccw`, `ExternalGearBelt*`) of parts already covered. `PivotSkirt` was the only unique build part and was kept |
| `.x3g` toolpaths | 14 | 104.7 | Makerbot machine code — not geometry, and not for any current printer |
| v1 legacy STL set | 68 | 56.4 | Superseded by the HD sets |
| Parasolid `.x_t` | 140 | 54.3 | **Byte-for-byte the same solids as the STEP files**, in a proprietary kernel format |
| HD set superseded by HD update | 57 | 30.2 | Earlier revision of a part kept elsewhere here |
| OnShape glTF renders | 21 | 6.9 | Display meshes of solids already kept as STEP |
| HD update, not in the build list | 18 | 3.3 | `Foot`, `EndArmHandle`, `KevlarGuide`, skins — no BOM row |

Git history is the version record going forward, so superseded revisions are not kept as files. Everything
above is recoverable from the upstream archives using the method below; nothing removed was unique except
where noted.

## How this was retrieved

Recorded so the mirror can be refreshed or a discarded file recovered. Thingiverse serves no per-file
download URL and blocks plain HTTP clients at the CDN; the working route was:

1. The public web-app token is embedded in Thingiverse's own JS bundle
   (`cdn.thingiverse.com/site/js/app.bundle.js`, exported as `YK`).
2. `api.thingiverse.com` rejects that token from a non-browser client (Cloudflare). The **same-origin
   proxy** at `https://www.thingiverse.com/api/...` accepts it, so requests must run from a browser
   context on the Thingiverse origin.
3. `GET /api/things/{id}/files?per_page=300` lists files; `GET /api/v2/files/{fileId}/download`
   redirects to a plain, unsigned, non-expiring `cdn.thingiverse.com/assets/...` URL.
4. Those CDN URLs fetch fine outside the browser **provided a browser `User-Agent` is sent** — without
   one the CDN answers `429`.

Source archives: [HD set](https://www.thingiverse.com/thing:3206154),
[HD update](https://www.thingiverse.com/thing:3781990),
[tool interface](https://www.thingiverse.com/thing:3166448),
[covers](https://www.thingiverse.com/thing:2842496),
[v1 legacy](https://www.thingiverse.com/thing:2108244),
[Dropbox in-work](https://www.dropbox.com/sh/5bdyhcyyrf3x53k/AAAagpOvq-TxkVKE1Ax-uodEa/STLs?dl=0).
OnShape retrieval is documented [separately](Reference/onshape-v1/README.md#how-this-was-retrieved).

## Regenerating

`PART-INDEX.md` and `MANIFEST.csv` are derived artifacts. Regenerate them after adding or replacing model
files, and re-check them whenever
[007.2](../../specs/007.2-Printed-Parts.md#regenerating-this-list) is regenerated.

## Licence

The Thingiverse sets are published by Haddington Dynamics under **GNU GPL**. They keep that licence here;
mirroring does not change it. The OnShape document is owned by a different account and states no licence —
see [its README](Reference/onshape-v1/README.md#licence) before redistributing those files.

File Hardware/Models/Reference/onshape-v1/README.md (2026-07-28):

# OnShape export — v1 design

Export of the public OnShape document that [007.2](../../../../specs/007.2-Printed-Parts.md#model-file-sources)
names as the CAD source. Retrieved 2026-07-26 with a signed-in (free-tier) OnShape account — the export
endpoints reject anonymous requests, which is why this could not be mirrored alongside the
[Thingiverse sets](../../README.md).

**This is reference material, not build material.** It is the superseded v1 robot, and it is not a
parametric model. Both claims are evidenced below.

| | |
|---|---|
| Document | **"Dexi"** — [2af8ed0e…](https://cad.onshape.com/documents/2af8ed0e61a34ebf69284c68/w/72caf65e51bde98e456925d2/e/6843c182cbf9181dbb307455) |
| Owner | Todd Enerson |
| Created | 2017-02-11 |
| Workspace | `72caf65e51bde98e456925d2` |
| Contents | 1 Part Studio (140 solids), 48 assemblies, 3 drawings |

## This is not a parametric model

⚠️ **The Part Studio contains exactly one feature — `Import 1`** — a `BTMParameterForeignId` pointing at
foreign CAD (`589eb21afb258f0f71a59f68`). All 140 solids arrived through that single import. There are no
sketches, no extrudes, no editable dimensions, and no feature history to recover.

Two consequences:

- **The STEP files here are the full fidelity OnShape holds.** Nothing is lost by working from them rather
  than from the OnShape document; there is no richer source behind them.
- **007.2's original description of OnShape as "the parametric source of record" was wrong.** It is a
  container for imported dead solids. The genuinely parametric source is whatever CAD system produced that
  import, and it is not in this document.

The original imported file is **not retrievable** — the foreign element ID returns `404` from every
blob-element and document endpoint tried. It was deleted, or it lives in a document that is not public.

`partstudio-features.json` holds the raw feature response, so this is checkable rather than taken on trust.

## This is the v1 design, not the HD build list

⚠️ Parts are numbered `KP00xx`/`KA00xx` — a scheme belonging to this document alone, unrelated to the
authoritative `PBS #` part numbering or to the `HDI-` CAD IDs
([007.2 § Part identifiers](../../../../specs/007.2-Printed-Parts.md#part-identifiers)). Matching the 87
`KP`-numbered parts against the STL sets by name, at the time those sets were still mirrored:

| Matches by name | Count |
|---|---|
| v1 legacy set | 40 |
| HD set | 8 |
| HD update | 7 |
| No name match in any STL set | 46 |

Only **11** distinct parts match the HD sets — the union, not the sum, since some match both. So this
document corresponds to the **superseded v1 robot**. Treat any part here as v1 geometry unless it is
confirmed against the current parts in [`Hardware/Models/`](../../README.md). Name matching is exact-stem,
so a part could exist under a different name — the counts bound the overlap, they do not prove identity.

## What this recovers that exists nowhere else

Of the 46 `KP` parts with no STL counterpart, about 40 are fabricated rather than bought. Two groups matter:

- **The differential mechanism internals** — `SideDifferentialGear`, `SideDifferentialGear2`,
  `OutterFrontDifferentialGear`, `InnerFrontDifferentialGear`, `SmallDifferentialShaft`,
  `DiffA1CodeDiskFine`. [007.2](../../../../specs/007.2-Printed-Parts.md) records the differential group as
  `[Provisional]` precisely because the in-repo GLTF contains only the differential **covers**, not the
  mechanism internals ([DC-2](../../../../specs/009-Design-Completion.md#differential-detail-design)). Those
  internals are here as solids. Since 007.2 also states the current differential group *realizes the
  previous version's differential as a working substitute*, this v1 geometry is directly applicable.
- **Strain-wave drive geometry** — `GearCSF-14-XXX-2A-R`, `CamLeverCSF-14-XXX-2A-R`,
  `KP0008-01_GearCupCSF-14-XXX-2A-R`, plus `CSF-14-2A-R FLEXSPLINE` and `14 WG BEARING` solids. Relevant to
  [DC-1](../../../../specs/009-Design-Completion.md#strain-wave-component-set), which turns on which
  vendor's component set the adapters are cut to.

Also unique here: slip-ring parts (`SlipRing`, `SlipRingBrushA`/`B`, `SlipRingBracketV2`), the wrist and
elbow shafts, and `ForarmBeam`.

## Layout

| Path | Files | What |
|---|---|---|
| `parts-step/` | 140 | Per-part **STEP** (ISO-10303-21). B-rep solids, readable by FreeCAD, Fusion, SolidWorks, anything |
| `assemblies/definition/` | 48 | Assembly JSON with occurrences, transforms, mate features and mate connectors |
| `assemblies/KA0006-01_Main_flattened.step` | 1 | The **whole robot**, flattened, in assembled positions |
| `parts-index.json` | — | `file` → part name, `partId`, `elementId`, `bodyType` |
| `elements.json` | — | All 52 document elements with type |
| `partstudio-features.json` | — | The raw feature list; evidence for the "single Import feature" claim above |

All 140 STEP files were verified to open with `ISO-10303-21` and close with `END-ISO-10303-21`, and all JSON
verified to parse.

**Two exported formats were dropped** when this directory was reorganized:

- **Parasolid `.x_t` (140 files, 54.3 MB)** — the same solids as `parts-step/`, in a proprietary kernel
  format. STEP is the ISO standard and opens in open-source tools, so nothing is lost.
- **glTF (21 files, 6.9 MB)** — display meshes of solids already held here as STEP.

Both are re-exportable from OnShape with the method below.

## How this was retrieved

OnShape's export endpoints (`/parasolid`, `/stl`, and the translation API) redirect cross-origin, so a
browser `fetch` on `cad.onshape.com` fails CORS. The route that worked, using the signed-in session:

1. Drive Playwright's **`page.request`** API context — it shares the browser cookie jar but is Node-side,
   so it follows redirects and is not subject to CORS. Session cookies never touch disk.
2. `GET /api/v6/parts/d/{did}/w/{wid}/e/{eid}/partid/{pid}/parasolid` returns Parasolid directly.
3. STEP needs the async translation API: `POST …/translations` with `formatName: STEP` (**requires the
   `X-XSRF-TOKEN` header** taken from the `XSRF-TOKEN` cookie, or it answers `401`), then poll
   `GET /api/v6/translations/{id}` until `requestState` leaves `ACTIVE`, then
   `GET /api/v6/documents/d/{did}/externaldata/{id}`.
4. Bytes were streamed to a loopback-only receiver that wrote them here.

## Licence

The OnShape document is public but carries no explicit licence grant. The Thingiverse sets by Haddington
Dynamics are GPL; **this document is owned by a different account and its terms are not stated.** Confirm
before redistributing these exports.

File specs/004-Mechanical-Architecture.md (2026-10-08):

# 004 — Mechanical Architecture

This document specifies the mechanical design of Dexter: the structural philosophy, the kinematic
chain, and the joint-by-joint drivetrain and structure. It implements the structural requirements
([002](002-Requirements.md#4-structural-and-mechanical-requirements)) and the geometry
([003](003-Kinematics.md)). The parts that realize it are listed in
[007-Bill-of-Materials.md](007-Bill-of-Materials.md); the procedure that builds it is
[008-Assembly.md](008-Assembly.md).

## Structural philosophy

Dexter is built as a **3D-printed body stiffened by bonded pultruded carbon fiber**. Printed parts form the
complex joint housings, motor mounts, and pulleys; straight structural spans are carbon-fiber square tubes
and flat "strakes" epoxy-bonded into printed sockets. This yields a light, stiff arm at low cost and with
desktop fabrication. The materials themselves are specified in the table below.

The design deliberately **tolerates drivetrain compliance**: because the position loop closes on the
joint's true output angle rather than on the motor shaft, the mechanics need not be perfectly stiff or
zero-backlash. This is what allows a mostly-printed arm to reach high precision, and it is the reasoning
behind REQ-PRE-1 — stated in full in
[002](002-Requirements.md#3-precision-and-performance-requirements) and realized as described in
[005](005-Electronics-and-Control.md#control-architecture).

## Kinematic chain

```mermaid
graph TD
    Base["Base (bolted mount) — J1 base rotation"]
    Pivot["Main Pivot — J2 shoulder pitch"]
    Arm["Arm Body (L2) — carries J3 drive + belt directors"]
    Elbow["External Gear / End Arm Hub — J3 elbow pitch"]
    Diff["Differential — J4 pitch + J5 yaw (wrist)"]
    Tool["Tool Interface — roll + grip"]
    Base --> Pivot --> Arm --> Elbow --> Diff --> Tool
```

Three strain-wave-driven joints (J1–J3) position the arm; a belt-driven differential (J4–J5) forms the
wrist; a two-axis tool interface acts at the end. Structural link spans L1–L5 are defined in
[003](003-Kinematics.md#link-lengths).

## Materials and construction methods

| Element | Design |
|---|---|
| Printed body | **Onyx / carbon-fiber-reinforced nylon**, printed on a desktop CF-capable printer; CF reinforcement ("CF" parts) on the highest-load housings |
| Structural spans | **Pultruded carbon fiber** — square tubes (1", 0.75") and flat strakes, epoxy-bonded into printed sockets |
| Load-bearing metal | The [base mounting plate](#base-mounting-plate) only — the one part of the robot not printed or bonded |
| Reductions J1–J3 | 52:1 strain-wave (harmonic) drives |
| Reduction J4–J5 | GT2 timing belts + printed/bonded pulleys driving a differential |
| Bearings | Standard metric ball bearings (trade sizes 68xx, 67xx, MRxxx) at every rotating interface |
| Fastening | M2/M3 hardware; threadlocker on structural threads; cross-pattern tightening on all multi-bolt joints |
| Bonding | Two-part epoxy (CF-to-printed structure), cyanoacrylate and hot glue (light captures) |

**Construction conventions** (apply throughout [008](008-Assembly.md)): bond CF spans with epoxy on both
mating surfaces; never tighten a multi-bolt interface sequentially — always cross/star pattern to seat parts
evenly; printed threads and aluminum motor bodies strip easily, so torque is limited and set screws are
brought up incrementally around the circle.

## Base (J1)

The base fixes the robot to the world and provides the J1 rotation axis.

**Mounting.** Dexter uses a **bolted base**: a rigid metal plate bolted to the Base Mount Bottom
(`BaseMountBottom_Bolted` / `HDI-110-001`) and through to a stable work surface. The mount must react the
arm's full dynamic load (REQ-ENV-5).

### Base mounting plate

| Property | Design |
|---|---|
| Material | **6061-T6 aluminium**. Steel is an acceptable alternative and adds desirable mass. Printed Onyx is **not** acceptable for a load-bearing plate |
| Thickness | **9.5 mm (3/8″)** in aluminium, ≈6 mm in steel |
| Footprint | **≈200 × 200 mm** square |
| Robot-side bolt pattern | **8 × M6 tapped through**, on the coordinates below |
| Work-surface bolt pattern | **4 × Ø6.6 mm clearance holes** at (±85.000, ±85.000) mm |

**Robot-side hole pattern.** The Base Mount Bottom presents a 150 × 150 mm flange, 10.000 mm thick, whose
eight mounting holes the plate is tapped to match. They are not on a bolt circle: they sit in pairs on the
flange's four edges, 25.000 mm apart and 62.500 mm out, so the pattern is unchanged by a 90° rotation of
the robot on its plate. Coordinates are from the J1 axis, in the plate's plane:

| | x (mm) | y (mm) |
|---|---|---|
| Pair on +y edge | ±12.500 | +62.500 |
| Pair on −y edge | ±12.500 | −62.500 |
| Pair on +x edge | +62.500 | ±12.500 |
| Pair on −x edge | −62.500 | ±12.500 |

**The bolt is M6 socket head cap, 8 off, 18 mm long.** It passes through the flange and takes 8 mm of
thread in the plate, leaving 1.5 mm of tapped depth unused so that nothing protrudes below the plate.

The flange is printed at **Ø6.000 through with a Ø10.000 × 6.0 mm counterbore** on its upper face, which
is under size for M6 on both diameters. The flange is therefore **opened on assembly to Ø6.6 through and
Ø11.0 counterbore** ([008.2](008-Assembly.md#0082-base)). The head seats on the counterbore floor and is
driven from inside the base, which is open above it.

**Stability rationale.** The worst-case static overturning moment — the arm fully extended, moving-link mass
lumped near mid-reach plus payload at full reach, with a ×2 dynamic factor — is ≈ **45 N·m**. A plate that
merely *rests* on the bench would need impractical mass to resist that: a 250 × 250 × 10 mm steel plate at
≈4.9 kg supplies only ≈6 N·m of restoring moment, so it tips. **The plate must therefore be fixed to the
work surface**, at which point the moment reacts as bolt tension of ≈300 N at the far bolt, well within an
M6's capacity. Through-bolting the four corner holes is the specified method; clamping the plate to a
T-slot table by the same corners is equivalent if each clamp is rated to that tension. **The base clamp is
not part of this load path** — it grips the strakes on the Base Mount's spigot and carries no
plate-to-bench load.

The work-surface fastener is **M6 bolt, property class 8.8 or better, with a plain washer under the head
and under the nut, and a nut — 4 sets**. Length is **9.5 mm plate + work-surface thickness + 12 mm** for
the washers, nut and thread run-out, rounded up to a stock length. The work surface must give access to
its underside for the nuts; where it does not, use the T-slot clamp alternative above.

**Design intent: the plate is a permanent bench fixture; the robot base bolts onto it and can be removed as
a unit while the plate stays fixed.**

**Base clamp.** The Base Long joins the Base Mount Bottom on the strakes epoxied into both
([008.2](008-Assembly.md#0082-base)), and **one** base clamp grips that joint.

The Base Mount Bottom's top 16.000 mm is a spigot, grooved for the six strakes, above a seating shoulder at
**82.000 mm** over its mounting face. The clamp is **15.000 mm** tall with a **Ø74.500 mm** bore, split on
one side; it seats on the shoulder, occupying **82.000 → 97.000 mm**, and its bore closes the strakes into
the spigot's grooves. It is tightened with one M3 × 20 mm bolt ([C-611](007.1-Parts-Catalog.md#6-fasteners))
across the split. The spigot has room for one clamp.

**The base stack.** The clamp sets no height. Each part above the mounting face seats on a face of the part
below it, so L1 ([003 § Link lengths](003-Kinematics.md#link-lengths)) is the sum of printed dimensions:

| Station | Height above the mounting face | Set by |
|---|---|---|
| Base Mount Bottom top face; the Base Long seats on it | 98.000 mm | `#110-001` |
| Base Long top face; the Base Motor End Cap's 6810 bottoms in the upper bore flush with it, and the Main Pivot's base rests on that bearing's inner race | 194.000 mm | `#120-001`, 96.000 mm tall |
| **J2 axis** | **231.500 mm = L1** | `#300-001`, axis 37.500 mm above its base |

**Base rotation drive.** J1 is driven by a strain-wave base motor (see below); the base structure carries
the Base Code Disk and stator for the J1 encoder and reduction.

*Source: wiki `Dynamics.md` (bolted base); CAD parts `HDI-110-001_BaseMountBottom`,
`HDI-110-002_BaseClamp`, and `HDI-220-001_BaseLong`, and their placements in the base chain; printed parts
`#120-001` and `#300-001` ([007.2](007.2-Printed-Parts.md)).*

## Base joints J1–J3: strain-wave drive

J1 (base rotation), J2 (shoulder pitch), and J3 (elbow pitch) each use a **52:1 strain-wave reduction**
driven by a microstepped stepper motor ([005](005-Electronics-and-Control.md#actuation)); the resulting
commanded step resolution is derived in
[006](006-Firmware-and-Calibration.md#drive-constants-axiscal). The strain-wave principle gives a high
ratio, compact, near-zero-backlash reduction — the reason these joints hold position precisely.

Each drive comprises the **strain-wave component set** — a flex spline, a wave generator, and a circular
("stator") gear — plus printed adapters (Wave Gen Coupler, Flex Spline Attach/Cap) that couple it to the
motor shaft and the printed joint output. J1 and J2 are built as the base and pivot motor assemblies; J3's
drive is the **External Gear** assembly, in which the harmonic motor turns an external gear ring at the
elbow. All three are the same reduction (identical `AxisCal`), unchanged from the previous version, so
**three identical component sets are required**.

The printed adapter interfaces are cut to match the commercial component set specified in
[C-201](007.1-Parts-Catalog.md#c-201--521-strain-wave-component-set), which states its identity, price,
lead time, and the mating dimensions the adapters are cut to, each cross-checked against the printed
adapter geometry. Procurement of the set is [DC-1](009-Design-Completion.md#strain-wave-component-set).

*Source: firmware `AxisCal`; wiki `Hardware.md`, `Joints.md`; factory maintenance note; HanZhen manufacturer
drawing (`Hardware/Reference/XB1-AS-C-32.pdf`).*

### Main Pivot (J2) and Arm Body (J3 support / L2)

The **Main Pivot** is the printed shoulder housing carrying the J2 encoder disk and the J2 pivot motor; its
short/long ends are stiffened with bonded CF strakes and it mounts onto the base via a pressed bearing and
all-thread tie rods. The **Arm Body** forms the L2 span (J2→J3) as a 1" CF square tube bonded into
a printed body, and additionally carries the **belt directors** — printed, bearing-guided pulleys that route
the J4/J5 drive belts along the arm to the differential. The L2 link length is specified in
[003](003-Kinematics.md#link-lengths); the tube cut length that realizes it is specified in
[C-504](007.1-Parts-Catalog.md#c-504--braided-carbon-fibre-square-tube-1) and listed in
[007.5](007-Bill-of-Materials.md#0075-arm-body). The socket carries a concentric 25.5 × 25.5 mm chamfered
mandrel inside its 29 mm pocket, so the tube is lapped on both faces of its wall rather than one.

## Wrist and differential (J4–J5)

J4 (wrist pitch) and J5 (wrist yaw) are the two outputs of a **differential**: two input pulleys driven in
common produce pitch, driven in opposition produce yaw. The inputs are two plain **NEMA-17 steppers** (the
"angle" and "rotate" motors, mounted in the External Gear Mount near the elbow) driving **GT2 timing belts**
that run forward along the arm through the belt directors to the differential's input pulleys. The
end-effector wiring bundle passes through the differential's hollow bore.

- **Belt reduction, not microstep oscillation.** The wrist obtains its resolution from a
  **physical pulley reduction** rather than from firmware microstep oscillation. The **net wrist reduction
  is 13.5:1**, fixed by the J4/J5 drive constant
  ([006](006-Firmware-and-Calibration.md#drive-constants-axiscal)), and it is realized in **two belt stages
  either side of the elbow**:

  | Stage | Driver | Driven | Ratio |
  |---|---|---|---|
  | 1 — along the arm | `#6A0-001` **16T** motor pulley | `#430-001`/`#430-002` **108T** External pulleys | 6.75:1 |
  | — | *elbow crossing: Ø8 rod (outer channel), strake tube (inner channel)* | | *1:1* |
  | 2 — along L3 | `#421-001`/`#421-002` **40T** Internal pulleys | `#720-003` and `#720-001`'s band, **80T** | 2.0:1 |
  | | | | **13.5:1** |

  Both channels are identical, so J4 and J5 see the same reduction. The differential itself is **1:1**
  (below) and contributes nothing to it, so the whole 13.5 is carried by the two belt stages. The belts
  that run them are [C-301 and C-302](007.1-Parts-Catalog.md#3-belts-and-pulleys).

  **Why this split.** Every feasible decomposition satisfies `N_ext × N_diff = 216 × N_int`, and `N_int` is
  held at its as-built **40T**: `#421-002` Internal Inner Pulley carries its tooth ring on a Ø17 6703 seat
  (Ø18 boss), because that bearing supports the strake tube inside `#410-002` New Belt Pulley, and a GT2
  ring enclosing Ø18 with any usable wall needs N_int ≥ 34 — which would force N_ext ≥ 184, a Ø117 mm
  pulley at the elbow. Shrinking the 16T motor pulley instead needs 8–12T, whose tip diameters
  (4.6–7.1 mm) are at or below the Ø5 motor shaft. The differential input pulley is therefore what grows,
  and with N_int at 40T the requirement is `N_ext × N_diff = 8640`.

  Net ratio — and therefore joint resolution, speed and stall torque — is identical for every solution.
  What moves is **where the reduction sits**: everything between the stages carries the intermediate
  torque, so a larger first stage loads the elbow crossing harder, while a larger second stage puts a
  bigger pulley at the wrist and pushes Diff Body A out against its cover.

  | | 90 / 96 | **108 / 80 — adopted** | 120 / 72 |
  |---|---|---|---|
  | Stage 1 (motor → External) | 5.625:1 | **6.75:1** | 7.5:1 |
  | Stage 2 (Internal → differential) | 2.4:1 | **2.0:1** | 1.8:1 |
  | Torque through rod + strake tube | 2.59 N·m | **3.10 N·m** | 3.45 N·m |
  | Stage-2 belt tension at stall | 203 N | **244 N** | 271 N |
  | Differential pulley tip Ø | 60.607 mm | **50.422 mm** | 45.329 mm |
  | Diff Body A width vs the cover's 73.5 mm | ≈74.6 — **over** | **63.0** (rendered) | ≈59.2 |
  | External pulley tip Ø | 56.788 mm | **68.247 mm** | 75.886 mm |

  Torque figures are motor stall (0.46 N·m,
  [C-101](007.1-Parts-Catalog.md#c-101--nema-17-stepper-09step)) taken through the stage lossless, and the
  tension is that torque at the 40T Internal pulley's pitch radius —
  comparative figures, not ratings. The rejected options' Body A widths carry that part's existing running
  clearance and wall thickness out to the new pulley radius, so they are ±2–3 mm: enough to order the
  options, not to build to. The adopted width is the rendered `config="revised"` part. **108 / 80 is adopted** because it leaves margin on both risks rather than spending all of it
  on either. 90/96 preserves every load path at today's values but drives Body A past the
  78 × 73.5 × 50.5 mm cover envelope that the [interface below](#differential-interface) fixes; 120/72
  keeps that envelope untouched but puts 33 % more torque through a printed tube bonded to three CF
  strakes, which nothing characterizes. The adopted split widens Body A from 60.0 to 63.0 mm inside a
  cover with 13.5 mm of headroom and raises the elbow torque 20 %; its stage 2 is exactly 2:1.

  `config="revised"` builds these counts; `config="previous"` builds the previous version's 90T External
  against 40T at the differential, netting 5.625:1, and is not printed
  ([DC-12](009-Design-Completion.md#wrist-pulley-rework)).
- **Differential detail.** The differential detail design is **authored** as parametric
  OpenSCAD source in [`Hardware/Models/700-Differential/`](../Hardware/Models/700-Differential/): one
  `.scad` per part beside its mesh, shared dimensions in `diff_params.scad`, placements in
  `diff_assembly.scad`, and a `render.json` that `render.rs` uses to render and verify every part. Two
  parameter sets are selectable: `config="revised"` meets the [interface below](#differential-interface)
  and is the default, the configuration the model set is worked on and printed from;
  `config="previous"` reproduces the previous version's built differential, is selected with `-D`, and
  is what the reference gates measure. Physical build validation
  (binding, wiring survival, code-disk reads) remains in
  [DC-9](009-Design-Completion.md#performance-characterization).

  The recreated parts are verified against their reference meshes surface by surface, with one decided
  exception on the Diff Gear Shaft's tooth form. The verification contract, the per-part measurements
  and that exception's reasoning are in [`Hardware/Models/README.md`](../Hardware/Models/README.md#verifying-a-recreated-part-against-its-reference).

  **Authored mechanism facts** (measured from the built part set, now fixed in `diff_params.scad`): all
  three bevels — Split Gear (output), Diff Gear Shaft, and Diff Gear Axle — are **20T straight bevels at
  1:1:1**, outside diameter **44.055 mm** (module ≈ 2.057 at 45° pitch cones), one shared crown definition
  carried by all three (a rebuild history recorded below). The Split Gear and the Diff Gear Axle are not
  two similar gears but **one gear placed twice**:
  sections of the Split Gear Top and the Diff Gear Axle taken
  15.4484 mm apart agree to 0.0001 mm over 4088 points, already clocked alike. The crown is therefore
  authored once, in `diff_bevel.scad`, from four measured cones — face `r = −1.14792 z`, root
  `r = −0.11121 − 0.84952 z`, heel `r = 49.82164 + 1.44761 z` and a 45° inner face, all stated about the
  gear's own apex — plus one cubic-Bézier tooth flank. **The Diff Gear Shaft's own reference carries the
  previous revision of that gear.** It is 20T and its root radius agrees at a given height, but its
  reference's top land ran `r = 1.18343 (y − 0.5068)` where this gear's face cone is `1.14792`, and its
  root cone `r = 0.84175 y` with the apex on the origin rather than `0.84952` offset 0.131 mm. The v1
  STEP identifies the form: it states one `CONICAL_SURFACE` of slope 1.1834163 and apex 0.5064895 in
  **all four** of its bevels, and the Diff Gear Shaft's mesh reproduces that to 1.4 × 10⁻⁵ in slope — so
  the revision that produced these references re-cut three gears and left this one behind, and it still
  meshed, on a form one revision old. The Diff Gear Shaft is now rebuilt to the shared crown instead
  ([CR-3A7](../CHANGES.md)), a matched set of four rather than a faithful copy of its own superseded
  reference — the **1:1:1 claim is exact for all three** positions. Both belt inputs are **80T GT2**
  pulleys in `config="revised"`: the Diff End Pulley, and the `#720-004` Diff Shaft Pulley ring keyed on
  the shaft's 40T band, which is the shaft's own input in `config="previous"`
  ([DC-12](009-Design-Completion.md#wrist-pulley-rework)); the Diff Gear
  Shaft doubles as the **J4 pivot axle** (its Ø25 section rides Diff Body A's 6705, its Ø17 rear journal
  the 6703); the Split Gear is **split along a 45° cone**, `r = z − 7` in its own frame — the Top half keeps
  what lies outside that cone and the Bottom half what lies inside it, the teeth running across the joint
  uninterrupted, which is why the halves must be clocked to each other on assembly by four Ø1.5 brads
  driven radially at **z = 12.750** — an axis the two references disagreed about by 0.5 mm and which the
  revised configuration settles on the Bottom half's value, `BRAD_Z` in `diff_params.scad`
  ([`Hardware/Models/README.md`](../Hardware/Models/README.md#what-assembling-the-set-showed)). The
  differential's inputs are driven by the 40T Internal pulleys through the elbow train, not by the 16T
  motor pulley.

### Differential interface

This is the **interface constraint set** the authored detail design satisfies (and any future revision must
keep satisfying). Envelope and axis figures are taken from the cover bodies and kinematic frames in
`dde/HDIMeterModel.gltf`, whose mesh vertices are in metres under a ×10 node scale and a ×100 root scale, so
world units are millimetres.

| Constraint | Value | Source |
|---|---|---|
| Outer envelope | `HDI-940-001_DiffCover` measures **78.0 × 73.5 × 50.5 mm**; `HDI-940-002_DiffCoverCap` seats on its +Y face, giving **≈78 mm across × 83 mm tall** stacked | GLTF cover bodies |
| J4 axis frame | `(0, 877.79, 18.00)` mm; the cover's own origin sits at `(0, 877.79, 0.50)` mm | GLTF `DexterHDI_Link4_KinematicAssembly` |
| J5 frame | `(0, 917.29, −2.00)` mm — **39.50 mm** from J4 along the arm axis, and not a point on the J5 axis (below) | GLTF `DexterHDI_Link5_KinematicAssembly` |
| Tool frame | `(54.82, 939.84, −2.00)` mm | GLTF `DexterHDI_Link6_KinematicAssembly` |
| Travel | Full J4 and J5 travel without binding; **J5's is the demanding one** for a mechanism routing wiring through its bore | [003 § Joint travel limits](003-Kinematics.md#joint-travel-limits) |
| Bevel ratio | **1:1** — the differential neither multiplies nor divides; the net 13.5:1 is realized entirely in the two belt stages | Three identical 20T crowns (above) |
| Input pulleys | **80T GT2**, tip Ø 50.422 mm, one per channel on the J4 axis. The pulley chamber in Diff Body A clears them | Stage 2 above; `#720-003`, `#720-004` ([DC-12](009-Design-Completion.md#wrist-pulley-rework)) |
| Encoders | Output-side optical code disks, **J4 = 115 slots, J5 = 100 slots**, read through the Angle and Rotate photointerrupter shrouds (`#824`, `#825`). J5's disk is `#710-004` (100 slots, counted on the model); **J4 has no disk — its 115 slots are cut into `#730-002` Diff Body B's mating rim** and read across the pivot from Diff Body A ([DC-11(e)](009-Design-Completion.md#the-j4-code-disk-is-missing)) | [003 § Joint definitions](003-Kinematics.md#joint-definitions), [005 § Sensing](005-Electronics-and-Control.md#sensing) |
| Through-bore | **6 conductors** pass the hollow centre and must survive J5's full travel | REQ-IF-4, [005 § Tool interface wiring](005-Electronics-and-Control.md#tool-interface-wiring) |

**The frame separation is L4.** The 39.50 mm above is the along-arm separation of the J4 and J5 stations,
which is the quantity [003 § Link lengths](003-Kinematics.md#link-lengths) specifies as L4 and states the
convention for. The 20.00 mm across-arm offset between the same two frames is real geometry that the
five-length kinematic model does not carry. Both are offsets between chain frames, not distances between
axes; which frame the wrist's one axis crossing is at is stated below.

**Body A's 81 mm axis lies along world y, down the forearm**, its −x end being the L3 spigot below. That
spigot is what orients the differential in the arm; the transform and everything it then measures are in
`Hardware/Models/robot_assembly.scad`, which owns the arm composition and the cover extents.

**Body A is inside the forearm skin, inside no wrist cover body, and a mating feature outranks a cover
extent.** The skin holds it with 6.5335 mm to spare on its tightest face. The three wrist boxes all end at
or below z = 18.000 while this axis runs at z = 36.000, and the skin begins on that same plane, so over the
wrist the two read as the halves of one shell split there. The spigot places the part, and what the wrist
boxes measure on their own is either a revision the printed differential does not match — as the Main
Pivot's and the Arm Body's already are — or a cover the measured set is missing.

**The reading that `HDI-950-001`/`-002` enclose Body A is withdrawn.** That cover's ±30.250 mm in x and z
about z = −2.000 is its own section about the tool axis, which begins at the J5 station and runs out to the
tool; it reproduces no plate of Body A's, and taking it for one placed the differential a quarter turn off
the spigot. An earlier revision compared Body A's 80.98 mm against `HDI-940-001`'s 78.0 mm and called that
an envelope violation; the two parts do not overlap — `HDI-940` spans z −32.5 to 18.0. The
`config="revised"` trim to 77.8 mm that violation produced was reverted on 2026-09-06 under
[CR-3A7](../CHANGES.md); `BODY_A_LEN` is 81.0 mm in both configurations.

**The wrist has no axis-to-axis distance.** The J4 and J5 axes **intersect**, at the differential centre —
inherent to a bevel differential, and the reason the measured DH set carries `a ≈ 0` on both wrist rows
([003 § DH model](003-Kinematics.md#denavithartenberg-model)). What the kinematic model carries across the
wrist is the station separation above, not a distance between two separated lines.

**That crossing is at the J4 frame, which makes the J5 frame a chain frame and not a point on the J5 axis.**
One intersection cannot sit at two frames 39.50 mm apart. It is at the J4 one, on four independent readings
set out at [DC-11(h)](009-Design-Completion.md#procurement-data); the first is that the differential's own
J4 axis then stands **307.500 mm** from J3 — the figure
[003 § Link lengths](003-Kinematics.md#link-lengths) and the firmware both hold — where placing it on the
J5 frame would stand it 39.500 mm further out, at 347.000 mm.
`Hardware/Models/robot_assembly.scad` places the assembly on that crossing and asserts it.

**The bevel apex sits `C = 48.5335 mm` above Diff Body A's base plane**, derived from the Diff Gear
Shaft's own apex and fixed by three separate seats in Body A that agree exactly: the rear 6703 face on the
Ø20 waist shoulder, the Ø27 collar 4 mm above the spacer step, and the 40T pulley band centred on the belt
slot. Body A's remaining datums are its 20 × 20 R4 section spanning z 1–21, its 6 × 6 belt slot at z 8–14,
and a shell mirror-symmetric about z = 11.000 over z ∈ [2, 20].

**Body A's 20 × 20 R4 arm is the L3 spigot** — the far end of the forearm tube, and the same plug the End
Arm Hub presents at the near end. The hub's measures 386.068 mm² in section over a 12.700 × 15.304 mm bore
of 131.7158 mm²; Body A's measures 386.245 mm² over the same bore, 131.7156 mm², the two bores agreeing to
two parts in a million. That bore is the belt passage both ends of an L3 span carry, and the six conductors
REQ-IF-4 routes to the gripper take the through-bore in the table above instead. The tube runs along world
y at (x = 0, z = 36.000) and Body A's spigot axis lands on (x = 0, z = 35.5335) — coaxial to 0.4665 mm,
the residual between the differential's own stack and the kinematic frame
([C-505](007.1-Parts-Catalog.md#c-505--braided-carbon-fibre-square-tube-075)). **The reading that this arm
is the tool mount is withdrawn**, and with it the claim that no link lands on Body A.

### End Arm Hub (J3–J4 region)

The **End Arm Hub** is the printed structure at the elbow/wrist transition: it houses the **axis
intersection** (where the J3 and downstream axes meet), the internal and external pulleys that transfer the
belt drives across the elbow, and the L3 span (J3→J4) as a 0.75" CF tube. As with the Arm Body, the L3 link
length is specified in [003](003-Kinematics.md#link-lengths) and its tube cut length in
[C-505](007.1-Parts-Catalog.md#c-505--braided-carbon-fibre-square-tube-075). The L3 joint is a spigot
rather than a socket: the tube slides over a printed plug on the hub.

## Tool interface (roll + grip)

The tool interface provides the two end-effector axes and is **cross-version compatible** — it has been
carried unchanged across every version of the robot, consistent with L5 being unchanged
([003](003-Kinematics.md#link-lengths)). It carries two
**Dynamixel smart servos** — a **roll** axis (tool rotation) and a **grip/span** axis (gripper) — commanded
over the tool interface serial bus ([005](005-Electronics-and-Control.md#actuation)). The printed body
mounts the servos, routes the 6-conductor tool cable, and carries the finger/gripper hardware (static and
dynamic fingers with replaceable grip pads).

## Open items by subassembly

A subassembly not listed here has nothing open.

| Subassembly | Joints | Drive | What is open |
|---|---|---|---|
| Arm Body (L2) | J3 support | belt routing | — |
| End Arm Hub (L3) | J3–J4 | belt transfer | External pulleys 108T in `config="revised"` — [DC-12](009-Design-Completion.md#wrist-pulley-rework) |
| Differential | J4, J5 | belt → differential | Input pulleys 80T in `config="revised"` — [DC-12](009-Design-Completion.md#wrist-pulley-rework) |

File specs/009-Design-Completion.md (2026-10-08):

# 009 — Design Completion

This document is the live list of **open design decisions** that must be closed to make Dexter
fully buildable and to advance its `[Provisional]`/`[TBD]` items to `[Specified]`. **It owns design
status.** No other document in the set carries status markers: each states its design as the design of
record and links here where something is still open, so anything not named below is `[Specified]`
([README.md](README.md#design-status)). Each item states the
requirement it must satisfy, its current state, what closing it requires (definition of done), and what it
blocks. These are design tasks owned by this project — not gaps in knowledge about the robot.

Each item covers only the part of a design that is still **open**. The settled design around it is
specified in the document named in the item's header, and is not repeated here.

Priority reflects lead time and build-blocking impact. Close **P1** items before ordering; **P2** before
cutting/committing structure; **P3** are refinements or characterizations.

**Sources of record.** Haddington Dynamics, the originator of this design, is **out of business**. No
further design files, part identities, or physical units can be obtained from them, and no serialized HDI
unit is available to measure. Every item below is therefore closed by one of four routes only: **recovery
from material already in this repository**, a **third-party procurement action**, a **decision authored into
this specification**, or a **measurement on a unit built from it**. The first route is narrow but real: it
closed [DC-10](#from-scratch-calibration-files), whose job files were committed with the design, deleted in
2020, and are restored from this repository's history. Where an item previously named recovery from the
originator, that route is gone and the item is an authoring task — most consequentially
[DC-2](#differential-detail-design), which became a full detail design, authored as OpenSCAD source that is
committed but does not yet reproduce its reference geometry.

| ID | Item | Priority | Blocks | What is still open | Status |
|---|---|---|---|---|---|
| DC-1 | [Strain-wave component set](#strain-wave-component-set) | **P1** | J1–J3 drives | — | `[Specified]` ✔ closed |
| DC-2 | [Differential detail design](#differential-detail-design) | **P1** | J4/J5 wrist | — | `[Specified]` ✔ closed |
| DC-3 | [Wrist reduction ratio](#wrist-reduction-ratio) | P2 | J4/J5 resolution | — | `[Specified]` ✔ closed |
| DC-4 | [Base plate](#base-plate) | P2 | Base mounting | — | `[Specified]` ✔ closed |
| DC-5 | [Link member lengths (L2/L3)](#link-member-lengths) | P2 | Arm Body, End Arm Hub | — | `[Specified]` ✔ closed |
| DC-6 | [Link-length discrepancy (L4)](#link-length-discrepancy-l4) | P2 | Kinematic accuracy | — | `[Specified]` ✔ closed |
| DC-7 | [Motor Control PCB](#motor-control-pcb) | P2 | Electronics | Physical power-on test | `[Provisional]` |
| DC-8 | [Power supply rating](#power-supply) | P2 | Power | — | `[Specified]` ✔ closed |
| DC-9 | [Performance characterization](#performance-characterization) | P3 | REQ-PRE/WS confirmation | The build [009.2](009.2-Test-Build-Manifest.md) specifies | `[TBD]` |
| DC-10 | [From-scratch calibration files](#from-scratch-calibration-files) | P2 | First bring-up | Running the calibration on a build | `[Provisional]` |
| DC-11 | [Procurement data](#procurement-data) | P2 | Ordering, printing | A coupon print | `[Provisional]` |
| DC-12 | [Wrist pulley rework](#wrist-pulley-rework) | P2 | J4/J5 drive parts | — | `[Specified]` ✔ closed |
| DC-13 | [Base height and L1](#base-height-and-l1) | P2 | Kinematic accuracy | — | `[Specified]` ✔ closed |
| DC-14 | [Power inlet mounting](#power-inlet-mounting) | P2 | Harness assembly | A mounting home for the panel receptacle | `[Provisional]` |

**Completion progress.** DC-1, DC-2, DC-3, DC-4, DC-5, DC-6, DC-8, DC-12, and DC-13 are closed. Every
other item has been narrowed to the gap named in the table above, and each of those gaps is one of two kinds
of work: **design authored here** (DC-14), or **a check on a physical build** (DC-7, DC-9, DC-10, DC-11).
DC-11 owes the model set neither a part nor a link, and all that is left of it is a coupon printed on the
machine that will print the robot. DC-2 — the largest single piece of work in
the set — is authored as parametric OpenSCAD source; all seven recreated parts now render as one clean
solid from measured geometry. Its physical-build checks remain with DC-9.

**DC-4 closed by measurement, and DC-13 closed the height it left.** The hole pattern is recovered exactly
from the CAD part; the model mirror held the previous version's un-bolted base and is corrected in place
([DC-11(i)](#procurement-data)). The J2 height the base stack sets is L1, specified from that stack under
[DC-13](#base-height-and-l1).

**DC-3 closed by decision, and DC-12 realized it.** The tooth-count split is carried by the parts that
`config="revised"` builds; `config="previous"` still builds the previous version's counts.

**DC-11(j) closed by decision, and it spawned DC-14.** Naming the inlet connector settled what plugs into
the robot but not what holds the receptacle: the part chosen is panel-mount and the design has no panel, so
the mounting home is tracked separately rather than left implicit inside a closed sub-item.

---

## Strain-wave component set
**DC-1 · P1 · Requirement: REQ-STR-2 · Specified in [004](004-Mechanical-Architecture.md#base-joints-j1j3-strain-wave-drive)** — ✔ **closed**

**Closed.** The part is identified and quoted. Vendor, part number, price, lead time, the interface
dimensions from the manufacturer drawing, and the cross-check against the printed adapters are specified in
[C-201](007.1-Parts-Catalog.md#c-201--521-strain-wave-component-set). Start this order before anything
else; it carries the longest lead time in the build.

Both halves of the drive are seated, from the shared
[`c201_spline_seat.scad`](../Hardware/Models/600-StrainWave/c201_spline_seat.scad): the circular spline by
the three Stator Holders' `config="revised"`, and the flexspline hub by the Flex Spline Attach's and Flex
Spline Cap's (`#630-005`, `#630-006`).

*Cone Drive (conedrive.com) remains a viable alternate source — same size-14, 52:1 spec, and the printed
adapters' `_ConeDrive`-suffixed CAD names and the maintenance schedule's Cone Drive lubricant
([006](006-Firmware-and-Calibration.md#maintenance)) reflect that this was the design's original target
vendor. HanZhen is the one actually quoted.*

**Definition of done — met:** a named, quotable part whose mating dimensions the printed adapters meet.
The adapters' `config="revised"` is checked by `render.rs --verify` for each group, and
[008.3](008-Assembly.md#0083-harmonic-drive-motors) steps 4–7 and 12 fasten the drive through it. What
remains is the order itself: the set is on 9–12 week lead time, and a physically received unit is confirmed
against the drawing before the final adapters are printed ([007.2](007.2-Printed-Parts.md)). `[Specified]`.

## Differential detail design
**DC-2 · P1 · Requirement: REQ-DOF-1, REQ-STR-3 · Specified in [004](004-Mechanical-Architecture.md#wrist-and-differential-j4j5)** — ✔ **closed**

**Closed by authoring.** There was no source to recover this design from, which is what made it an
authoring task rather than a retrieval one. The in-repo CAD model (`dde/HDIMeterModel.gltf`) carries the
differential *covers* and the kinematic frames but **not** the mechanism internals — which is why the
envelope and axis frames are specified in
[004 § Differential interface](004-Mechanical-Architecture.md#differential-interface) and nothing else is.
The OnShape document exported to
[`Hardware/Models/Reference/onshape-v1/`](../Hardware/Models/Reference/onshape-v1/README.md) is the **v1**
design and holds a single `Import 1` feature pointing at foreign CAD that returns `404`: measurable
reference geometry, not a parametric source. And no physical unit is obtainable — see **Sources of
record** above.

The design that closed it is specified in
[004 § Wrist and differential](004-Mechanical-Architecture.md#wrist-and-differential-j4j5), and its
geometry is owned by the parametric source in
[`Hardware/Models/700-Differential/`](../Hardware/Models/700-Differential/), organized as 004 describes.
The rules that verification is held to, the per-part measured state, and
the reference-export traps that make a naive comparison misleading are in
[`Hardware/Models/README.md`](../Hardware/Models/README.md#verifying-a-recreated-part-against-its-reference).

**Still outstanding under the contract:** `#730-002` Diff Body B is rebuilt from measurement but is not
yet in `DIST_GATES`. Its p95 is inside tolerance in both directions and only the maxima fail, both on the
same unmodelled feature — the chimney base's junction with the chimney cone, filleted on the reference and
sharp in the model. Filleting those four junctions is the remaining work.

**Definition of done — met:** a differential design authored to
[004 § Differential interface](004-Mechanical-Architecture.md#differential-interface), with its **source
geometry committed to this repository** (`.scad`, per the convention in
[`Hardware/Models/README.md`](../Hardware/Models/README.md#moving-to-openscad)) rather than as a mesh
alone, and geometrically verified against its references. The physical checks — J4 and J5 moving without
binding through full travel, the 6-conductor bundle surviving J5's travel, and both code disks reading
cleanly — are [DC-9](#performance-characterization)'s first-build checklist. Until a build passes those,
treat printed fit (press interference, bevel backlash) as tunable via `diff_params.scad`. Status
`[Specified]`.

## Wrist reduction ratio
**DC-3 · P2 · Requirement: REQ-STR-3, REQ-PRE (J4/J5) · Specified in [004](004-Mechanical-Architecture.md#wrist-and-differential-j4j5), [006](006-Firmware-and-Calibration.md#drive-constants-axiscal)** — ✔ **closed**

**Closed by decision.** No surviving record states how the net wrist ratio is decomposed into belt stages,
and none can be obtained (see **Sources of record** above), so the decomposition was authored here. The
two-stage tooth-count split, the measured constraint that forced the differential input pulley to grow,
and the options weighed against it are specified in
[004 § Wrist and differential](004-Mechanical-Architecture.md#wrist-and-differential-j4j5); the belt
lengths that follow from it are in [007.1 § 3](007.1-Parts-Catalog.md#3-belts-and-pulleys). The **net**
ratio was never the open part — it is fixed by the J4/J5 `AxisCal`
([006](006-Firmware-and-Calibration.md#drive-constants-axiscal)).

**Definition of done — met:** the tooth-count decomposition chosen, together with the belt lengths that
follow from it. `[Specified]` for the ratio and the tooth counts. The two belt lengths stay
`[Provisional]`: they stand on a routing no file in this repository places, and are confirmed against the
measured centre distance on the first build before ordering. The parts that must be re-cut to realize the
decomposition are [DC-12](#wrist-pulley-rework); resolution, range and backlash on a physical build are
[DC-9](#performance-characterization). Print the wrist pulleys from `config="revised"` only — see DC-12.

## Wrist pulley rework
**DC-12 · P2 · Requirement: REQ-STR-3 · Specified in [004](004-Mechanical-Architecture.md#wrist-and-differential-j4j5)** — ✔ **closed**

**Closed by authoring.** `config="revised"` builds the tooth counts that
[004 § Wrist and differential](004-Mechanical-Architecture.md#wrist-and-differential-j4j5) specifies.
`config="previous"` builds the previous version's 16T → 90T ‖ 40T → 40T = 5.625:1 train, which does not
match `AxisCal` = 86400 ([006](006-Firmware-and-Calibration.md#drive-constants-axiscal)); it is kept as the
reference the `dist` gates measure against and is not printed. Every printed GT2 tooth ring takes its form
from one shared definition, [`gt2_pulley.scad`](../Hardware/Models/gt2_pulley.scad), which derives tip and
root diameters from the tooth count.

| Part | `previous` | `revised` | Source |
|---|---|---|---|
| `#430-001` External Outer Pulley | 90T | **108T** | [`430-001_ExternalOuterPulley.scad`](../Hardware/Models/400-EndArm/430-001_ExternalOuterPulley.scad) |
| `#430-002` External Inner Pulley | 90T | **108T** | [`430-002_ExternalInnerPulley.scad`](../Hardware/Models/400-EndArm/430-002_ExternalInnerPulley.scad) |
| `#720-003` Diff End Pulley | 40T | **80T** | [`720-003_DiffEndPulley.scad`](../Hardware/Models/700-Differential/720-003_DiffEndPulley.scad) |
| `#720-004` Diff Shaft Pulley | — | **80T** | [`720-004_DiffShaftPulley.scad`](../Hardware/Models/700-Differential/720-004_DiffShaftPulley.scad) |
| `#720-001` Diff Gear Shaft | 40T input band | 40T spline band carrying `#720-004` | [`720-001_DiffGearShaft.scad`](../Hardware/Models/700-Differential/720-001_DiffGearShaft.scad) |
| `#730-001` Diff Body A | measured chamber | opened pulley chamber | [`730-001_DiffBodyA.scad`](../Hardware/Models/700-Differential/730-001_DiffBodyA.scad) |

`#421-001` and `#421-002` stay at **40T** — the Internal pair is what the decomposition holds fixed.

The Diff Gear Shaft's 80T input is the separate ring `#720-004`: the shaft enters Diff Body A through the
6705's Ø25 bore, which an 80T ring cannot pass. The ring keys on the shaft's 40T band as a spline and is
set into the chamber before the shaft ([008.6](008-Assembly.md#0086-differential)). Diff Body A's M3
screws sit outboard of the ring. Each part's dimensions, clearances, and what it keeps from its reference
are stated in its `.scad` file.

[`render.rs --verify`](009.3-Render-Program.md) verifies the revised set: every
revised part renders as one clean solid, the tooth counts are counted on the rendered meshes, the extents
`diff_assembly.scad` places by agree with the renders, and Diff Body A's intersection with `#720-004` is
empty. [`robot_assembly.scad`](../Hardware/Models/robot_assembly.scad) asserts Diff Body A inside the
forearm skin in both configurations.

**Definition of done — met:** the five parts re-cut in `config="revised"`, every part rendering as one
clean solid and previewing without warnings, Diff Body A asserting inside the envelope, the `previous`
config and its `dist` gates untouched, and `diff_assembly.scad` placing the enlarged pulleys without
interference. No file in this repository places the External pulleys against the elbow, so their
clearance there is confirmed on the first build together with the belt lengths
([DC-3](#wrist-reduction-ratio)). `[Specified]`.

## Base plate
**DC-4 · P2 · Requirement: REQ-STR-4, REQ-ENV-5 · Specified in [004](004-Mechanical-Architecture.md#base-j1)** — ✔ **closed**

**Closed.** The robot-side hole pattern, the bolt, and the base stack are specified in
[004 § Base mounting plate](004-Mechanical-Architecture.md#base-mounting-plate); the hardware quantities
are in [007.2](007-Bill-of-Materials.md#0072-base). The plate is `#110-004`, with parametric source and a
render-and-check script at
[`Hardware/Models/100-Base/`](../Hardware/Models/100-Base/110-004_BaseMountingPlate.scad); `render.rs --verify`
gates its eight tapped centres against `110-001_BaseMountBottom.stl`.

**Definition of done — met:** a plate drawing carrying the robot-side hole coordinates, and the resulting
hardware quantities in [007.2](007-Bill-of-Materials.md#0072-base). The load check — that the mounted
plate reacts full dynamic load without walking or tipping — is a measurement on an instrumented unit and
is held by [DC-9](#performance-characterization). `[Specified]`.
## Link member lengths
**DC-5 · P2 · Requirement: REQ-WS-6 · Specified in [003](003-Kinematics.md#link-lengths), [004](004-Mechanical-Architecture.md)** — ✔ **closed**

**Closed.** L2 and L3 are each a carbon-fibre tube bonded between two printed parts. Both cut lengths are
specified in [C-504](007.1-Parts-Catalog.md#c-504--braided-carbon-fibre-square-tube-1) and
[C-505](007.1-Parts-Catalog.md#c-505--braided-carbon-fibre-square-tube-075), each stated against the two
stops it bridges, and listed against their subassemblies in
[007.5](007-Bill-of-Materials.md#0075-arm-body) and [007.7](007-Bill-of-Materials.md#0077-end-arm-hub).
The glue rigs that hold each span at its finished spacing while the epoxy cures are catalogued in
[007.2 § Tooling](007.2-Printed-Parts.md#tooling--glue-rigs).

**Definition of done — met:** both cut lengths closed on measured geometry — L2 stop to stop through
`#410-001`, L3 from the End Arm Hub's spigot against the J3–J4 separation. L3's far end wants neither a
part nor another cut: [DC-11(h)](#procurement-data) closed it on Diff Body A's spigot, which the specified
243.0 mm laps by 15.000 mm. Confirmation on a built arm belongs to
[DC-9](#performance-characterization). `[Specified]`.

## Link-length discrepancy (L4)
**DC-6 · P2 · Requirement: REQ-WS-6 · Specified in [003](003-Kinematics.md#link-lengths)** — ✔ **closed**

**Closed by analysis.** L4 is **39.50 mm**, the along-arm separation of the J4 and J5 stations, specified
together with the convention it follows from in [003 § Link lengths](003-Kinematics.md#link-lengths). Both
records this item was opened against are disposed of there: the firmware file's 59.50 mm is that span's
along-arm and across-arm components added together, and the wiki's pair is version 1's set rather than a
reading of this version. The readings withdrawn on the way, the DH `d` term among them, are recorded in
[CR-3A12](../CHANGES.md#cr-3a12-l4-specified-along-the-arm-the-dh-d-corroboration-withdrawn).

**Definition of done — met:** the datum this item turned on — where L3 lands on the J4 axis — is the J4
station, which the same kinematic chain places 307.500 mm along the arm from J3, reproducing L3 exactly. It
does not depend on what closes the span between the L3 tube and Diff Body A's spigot:
[DC-11(h)](#procurement-data) closed that span on the spigot itself, and put the differential's own J4 axis
on this same station, reaching 307.500 mm from the other direction. What remains is confirmation on a built
arm — measured with [DC-9](#performance-characterization)'s first-build checks — and the one firmware field
that follows from it ([006](006-Firmware-and-Calibration.md#firmware-defaults-defaultsmake_ins)).
`[Specified]`.

## Base height and L1
**DC-13 · P2 · Requirement: REQ-WS-6 · Specified in [003](003-Kinematics.md#link-lengths), [004](004-Mechanical-Architecture.md#base-mounting-plate)** — ✔ **closed**

**Closed by analysis.** L1 is **231.50 mm**, the height of the J2 axis above the mounting face, specified
in [003 § Link lengths](003-Kinematics.md#link-lengths). It is set by the base stack specified in
[004 § Base mounting plate](004-Mechanical-Architecture.md#base-mounting-plate), where every height rests
on a face the next part seats on. The clamp is not in that stack, so it does not move L1, and the spigot
the clamp fits has room for one. The firmware file's 235.20 mm is a
height no seated stack of the build's parts produces; it is superseded, and
[006](006-Firmware-and-Calibration.md#firmware-defaults-defaultsmake_ins) carries the line to write. The
evidence, and the doubled clamp withdrawn with it, are recorded in
[CR-3A19](../CHANGES.md#cr-3a19-l1-specified-from-the-base-stack-the-doubled-clamp-withdrawn-6810s-allocated-to-their-seats).

**Definition of done — met:** L1 specified against a stack of positive stops, and
[003 § Link lengths](003-Kinematics.md#link-lengths) and the `LinkLengths` line reconciled to it.
Confirmation on a built base, and of J3's drive stack, belongs to
[DC-9](#performance-characterization)'s base checklist.
`[Specified]`.

## Motor Control PCB
**DC-7 · P2 · Requirement: REQ-CTL-3, REQ-IF-4 · Specified in [005](005-Electronics-and-Control.md#boards)**

**Open:** a physical power-on test. No purpose-built Motor Control PCB exists, so the previous version's
"green" board is reused. Its devices, its full connector map, and the board landing of every tool conductor
are specified in [005 § Boards](005-Electronics-and-Control.md#boards) and
[005 § Tool interface wiring](005-Electronics-and-Control.md#tool-interface-wiring) from the schematic; that
review is what established the reuse as viable, since the board's connector set is generic and the only
known difference is the harness White-wire reassignment. What has *not* happened is running a unit on it.

**Definition of done:** confirm the inherited board drives a unit correctly with this wiring harness on a
physical power-on test:

1. **Before power.** White lands on `J24` pin 2 with nothing at the tool end driving it; exactly one
   opto-supply jumper is fitted; every motor and opto lead is on the header its joint *name* selects
   ([008.10](008-Assembly.md#00810-wire-harness)).
2. **Under power.** Each of the five joints steps in the commanded direction and its own encoder counts
   with it — the check that the channel map was followed rather than the connector numbering.
3. **Measure the rail at `J23`** while the board runs. The fan is already chosen and spans 4.5–13.8 V
   ([C-716](007.1-Parts-Catalog.md#7-electronics-and-wiring)), so this reading confirms the rail rather than
   selecting the part — but a reading outside that span is a board fault, not a fan question.

Full closure (a purpose-built board) is a roadmap item ([011](011-Roadmap.md)), not a blocker here. If a
unit shows power-related faults absent on earlier builds, revisit this reuse assumption first.
`[Provisional]`.

## Power supply
**DC-8 · P2 · Requirement: REQ-CTL-5 · Specified in [005](005-Electronics-and-Control.md#power)** — ✔ **closed**

**Closed.** The supply rating was open because the board's input ceiling had not been established. It has
been, so the rating, the reasoning behind it, and the under-voltage failure mode are specified in
[005 § Power](005-Electronics-and-Control.md#power), the part is listed in
[007.10](007-Bill-of-Materials.md#00710-wire-harness), and an orderable part meeting that rating is named
in [C-103](007.1-Parts-Catalog.md#c-103--power-supply-36-v-dc). REQ-CTL-5 is `[Specified]`.

*(The in-testing "blue" board would raise the ceiling to 75 V — out of scope for this design.)*
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

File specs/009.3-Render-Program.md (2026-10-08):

# 009.3 — Render Program

This document owns the behaviour of the single program that renders and verifies the printed-part
meshes under `Hardware/Models/`, the schema of the per-group `render.json` config it reads, and the
rules by which it runs work in parallel. It replaced the per-group `render-all.rs` scripts, the
`700-Differential/render-meshes.rs` script, `100-Base/check.rs` and `700-Differential/parts.json`, which are deleted.

## Goals

- One program serves every mesh group. A new group adds a `render.json` and no code.
- Group-specific data (part lists, reference meshes, tolerances, probe points, counts) lives in the
  group directory, never in the program.
- Independent OpenSCAD renders run concurrently, because a single OpenSCAD process uses one core.

## Command line

```
render.rs <group-dir | all> [--meshes] [--verify] [--config previous|revised]
                            [--jobs N] [--only ID] [--fail-fast]
```
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

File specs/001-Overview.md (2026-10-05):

# 001 — Overview

Dexter is an open, high-precision robotic arm: a five-axis
carbon-fiber-and-3D-printed manipulator with a two-axis end effector, driven by stepper motors through
strain-wave and belt reductions, and closed-loop controlled by an FPGA that reads a high-resolution
optical encoder on the output side of every joint. It is designed to deliver near-industrial positioning
precision at a fraction of the cost and mass of a comparable industrial arm.
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

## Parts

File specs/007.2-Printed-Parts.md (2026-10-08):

# 007.2 — 3D Printed Parts

This document is the **de-duplicated print list for one complete robot**: every 3D-printed part, once, with
the quantity to print and a pointer to its model file. It is the fabrication counterpart to
[007.1-Parts-Catalog.md](007.1-Parts-Catalog.md), which covers everything that is bought rather than
printed.

It is a **derived artifact**, generated from [007-Bill-of-Materials.md](007-Bill-of-Materials.md). See
[Regenerating this list](#regenerating-this-list).

## Totals

| | Distinct parts | Pieces to print |
|---|---|---|
| Robot | **70** | **108** |
| Tooling (glue rigs + solder jigs) | 10 | 11 |
| **Total** | **80** | **119** |

Tooling pieces are jigs only; no robot part is duplicated for them. They are counted separately so a build
that skips the jigs does not over-print.

## Material

**Onyx (Markforged)** is the material of record for this generation of the design — the previous
generation printed in PLA, HD and later in Onyx. Parts whose model filename carries **"CF"** are printed
with **continuous carbon fibre reinforcement** (Markforged Mark Two class), not plain Onyx.

The printed parts are **scaffolding, not primary structure** — carbon fibre strakes and tubes
([007.1 §5](007.1-Parts-Catalog.md#5-structural-composites-and-metal-stock)) carry load between joints, and
the printed bodies locate them ([004](004-Mechanical-Architecture.md)). Two consequences bound any material
substitution:

- **Printed threads and thin captures strip easily.** [004](004-Mechanical-Architecture.md) limits torque
  throughout for this reason. A weaker filament narrows an already narrow margin.
- **The [base mounting plate](007.1-Parts-Catalog.md#c-509--base-mounting-plate-stock) must not be
  printed** in any material — it is the one load-bearing metal part in the robot.

### Print profile

The original parts were produced on Markforged equipment with settings that were never published, so the
profile below is **derived from the features the parts have to hold** rather than recovered. Each parameter
states the geometry that sets it, so a builder on different equipment can re-derive it rather than copy it.

| Parameter | Value | What sets it |
|---|---|---|
| Nozzle | **0.40 mm or finer** | The narrowest land in the set is between encoder slots: `#730-002`'s J4 track runs 0.800 mm slots on a 360/115 pitch from r 24.500, leaving **0.539 mm** of material at the inner radius — 1.35 extrusion widths at 0.40 mm. Slice the code disks and `#730-002` with variable-width perimeters, or fit a 0.25–0.30 mm nozzle for them |
| Layer height | **0.125 mm**, or 0.100 mm | The thinnest axial feature in the set is the [Belt Director](#arm-body-and-belt-directors--0075)'s 0.500 mm locating head. Both values divide it exactly; 0.2 mm does not, and builds it 2.5 layers thick |
| Perimeters | **≥ 4**, and **solid** through every press fit | A bearing seat carries its load in hoop tension across a race only 2.5–7.0 mm wide ([007.1 §4](007.1-Parts-Catalog.md#4-bearings)). Infill reached by a press fit yields and the seat goes loose. No bearing bore, strake slot, or CF tube socket may have infill within 1.6 mm of its wall |
| Infill | **≥ 40 %** | Same reason, one step out: the printed bodies are scaffolding, but the fits in them are not |
| Orientation | Bearing-bore and strake-slot axes **parallel to Z** | A bore whose axis lies in the build plane is formed by stacked layers and stair-steps; the same bore built about Z is formed by in-plane perimeter motion, which is where the machine's accuracy is. Where two fits on one part disagree, the bearing seat wins — the strake slot is a bonded joint with an epoxy gap, the seat is not |
| Dimensional compensation | **Zero in the slicer** | The model carries the machine's fit in its two [print-fit clearances](#print-fits), tuned on the coupon below. A slicer hole/contour offset as well would count the machine's error twice |

### Print fits

Every printed part's `config="revised"` draws each mating feature at its mate's nominal size, less or more a
clearance per side from one library,
[`print_fit.scad`](../Hardware/Models/print_fit.scad):

| Class | Default, per side | Applies to |
|---|---|---|
| **Press** | **0.05 mm** | A printed part against a bought part it is seated on, located by or bonded to: bearing seats and journals, the motor lugs, the circular spline's recess and step, the flexspline hub's spigot and nubs, and the bores, slots and spigots a CF rod, CF tube or strake is bonded to |
| **Slip** | **0.15 mm** | A printed part against another printed part, whatever the fit does: the Pivot Stator Holder's body in the Arm Body, the Ex Gear Stator Holder's core and keys in the External Gear, the Diff Keeper on Diff Body B's tube, and the Diff Shaft Pulley over the Diff Gear Shaft's band. And every fastener's clearance: screw holes, nut traps and pockets |
| **Running** | **0.50 mm** | Not a fit: a gap between two printed parts that turn past each other and must never touch, measured normal to the surface. `#730-002` Diff Body B against the toes of the three bevel crowns that turn in it — `#720-002`, `#720-001` and the Split Gear — each held off the volume its teeth sweep |

A fit's class follows its mate. A bought part is made to size, so a fit against it leaves room for one
printed surface's error; two printed parts each bring their own. A running gap also allows for the play
in the bearings that carry the moving part, so it is wider than either.

- A feature whose drawn gap already reaches its class's clearance keeps the gap it has.
- `config="previous"` draws no clearance, because it is the reference mesh its dist gate measures.
- Each part's header lists its fits and their classes. `render.rs --verify` probes every listed
  fit for an open gap with a wall behind it, at whatever clearances `print_fit.scad` holds.
- **No clearance is drawn on:**
  - the [base mounting plate](007.1-Parts-Catalog.md#c-509--base-mounting-plate-stock), which is
    machined;
  - the glue rigs, whose registers are precision fits by design
    ([§ Tooling — glue rigs](#tooling--glue-rigs));
  - the Split Gear's brad holes, which are interference fits by design;
  - face and shoulder contacts;
  - the tool interface set, whose source is Fusion rather than OpenSCAD.

**The coupon that qualifies a machine** is
[`950-Tooling/fit_coupon.scad`](../Hardware/Models/950-Tooling/fit_coupon.scad). It carries each fit class
exactly as the parts draw it. It does not carry the running gap, because a gap whose surfaces never meet
is not a fit a machine can fail:
- an MR128 seat at the press clearance (the `SEAT_D` of
  [`720-001_DiffGearShaft.scad`](../Hardware/Models/700-Differential/720-001_DiffGearShaft.scad));
- `#710-001`'s slot for the [C-502](007.1-Parts-Catalog.md#c-502--carbon-fibre-strip-092--220) strake,
  at the press clearance;
- a Ø8 bore at the press clearance, for the
  [C-506](007.1-Parts-Catalog.md#c-506--carbon-fibre-round-tube-8-mm-od--6-mm-id) tube;
- a printed peg with a bore at the slip clearance.

A machine is qualified when:
- the bearing presses in without a reamer;
- the strake enters the slot, and the tube the bore, by hand, without rocking;
- the peg slides through the slip bore.

A fit that fails is corrected by editing its clearance in `print_fit.scad` and printing the coupon again,
never by sanding parts. The coupon carried a 1.45 × 4.50 mm slot until
[DC-11(e)](009-Design-Completion.md#procurement-data): that is the C-503 *strip's* section, not any slot
in the robot, and a slot cut to it could not be passed. Qualification is
[DC-11(d)](009-Design-Completion.md#procurement-data).

## Model file sources

The **differential (700 series) is authored in this repository** as parametric OpenSCAD — see the
[differential part list](#differential--0076); for those nine parts the `.scad` file is the source of
record and the mesh is output. Every other part traces to an inherited archive, and **no archive offers a
per-part download URL**: the table below says which archive holds which family of parts, and the
[part list](#printed-parts) links each part to the file the mirror holds it as.

| Source | Contents | Link |
|---|---|---|
| **Dexter HD STL set** | The main printed-part set — most of the 100–800 series | [thingiverse.com/thing:3206154](https://www.thingiverse.com/thing:3206154) |
| **Dexter HD update** | Revised parts issued after the main set — check here first for any part in both | [thingiverse.com/thing:3781990](https://www.thingiverse.com/thing:3781990) |
| **V2 Tool Interface** | 900/911/912/920 series (tool interface, roll, span, gripper) | [thingiverse.com/thing:3166448](https://www.thingiverse.com/thing:3166448) |
| **Covers / skins** | Optional 9xx cosmetic covers — **not in the [007](007-Bill-of-Materials.md) build list** | [thingiverse.com/thing:2842496](https://www.thingiverse.com/thing:2842496) |
| **Dexter v1 (legacy)** | Superseded — for reference only | [thingiverse.com/thing:2108244](https://www.thingiverse.com/thing:2108244) |
| **OnShape CAD** | ⚠️ **Not a parametric source, and not this design.** The **v1** robot as 140 dead imported solids — one `Import 1` feature, no sketches, no editable dimensions, no feature history. Measurable reference only; mirrored in-repo at [`Hardware/Models/Reference/onshape-v1/`](../Hardware/Models/Reference/onshape-v1/README.md) | [cad.onshape.com — "Dexi"](https://cad.onshape.com/documents/2af8ed0e61a34ebf69284c68/w/72caf65e51bde98e456925d2/e/6843c182cbf9181dbb307455) |
| **Fusion 360 kinematic model** | Bare kinematic model; exports to STEP, IGES, STL, OBJ and others | [a360.co/3eoAQqo](https://a360.co/3eoAQqo) |
| **In-work STLs** | Updated / in-progress revisions | [Dropbox — STLs](https://www.dropbox.com/sh/5bdyhcyyrf3x53k/AAAagpOvq-TxkVKE1Ax-uodEa/STLs?dl=0&lst=) |
| **In-repo GLTF** | `HDI-` series kinematic and outer-skin geometry, including the `_ConeDrive` stator interfaces | `dde/HDIMeterModel.gltf` (and `dde/sim2/HDIMeterModel.gltf`) |
| **In-repo STL** | Pivot wire cover | `dde/doc/build_dexter/PivotWireCoverA_v1.stl` |
| **In-repo JSCAD** | End-effector mount, parametric | `official/Hardware/EndEffector/mount.jscad` |
| **In-repo OpenSCAD** | The differential (700 series), parametric and authored here — [the differential part list](#differential--0076) | [`Hardware/Models/700-Differential/`](../Hardware/Models/700-Differential/) |

**The upstream archives are mirrored in-repo, and the part list links each part to its own file.** Every
printed part a build needs is held in [`Hardware/Models/`](../Hardware/Models/README.md), organized by
component and indexed with a SHA-256 manifest, so an archive going away no longer takes the robot's
geometry with it. Each row of the [part list](#printed-parts) carries that file in its `Model` column,
and the table above says which archive it came from. **Which file belongs to which part is owned by
[`PART-INDEX.md`](../Hardware/Models/PART-INDEX.md)**, which also carries what is known about the matches
that rest on a filename alone; the `Model` column is generated from it.

### Part identifiers

Three numbering schemes appear in this document, and only one names every part:

- **`PBS #`** — **the authoritative part number.** It is the only scheme covering all 70 printed parts, and
  the one [007](007-Bill-of-Materials.md), [007.1](007.1-Parts-Catalog.md), [008](008-Assembly.md) and the
  [`Hardware/Models/`](../Hardware/Models/README.md) file names all key on. A part number alone locates its
  file.
- **`HDI-` / `TI1-` CAD IDs** — body names in the GLTF model, given in the `CAD ID` column where known.
  They cover only 13 of 70 parts, so they identify a part but cannot enumerate the set.
- **`KP` / `KA` numbers** — the superseded **v1** design in
  [`Hardware/Models/Reference/onshape-v1/`](../Hardware/Models/Reference/onshape-v1/README.md). These belong
  to no current part and are reference geometry only.

---

## Printed parts

### Base — [007.2](007-Bill-of-Materials.md#0072-base)

| PBS # | Part | Qty | Model | CAD ID | Source |
|---|---|---|---|---|---|
| #100-001 | Base Clamp | 1 | [`100-001_BaseClamp.stl`](../Hardware/Models/100-Base/100-001_BaseClamp.stl) | `HDI-110-002_BaseClamp` | HD set |
| #100-002 | Base Code Disc | 1 | [`100-002_BaseCodeDisc.stl`](../Hardware/Models/100-Base/100-002_BaseCodeDisc.stl) | — | HD set |
| #100-003 | Pivot Skirt | 1 | [`100-003_PivotSkirt.stl`](../Hardware/Models/100-Base/100-003_PivotSkirt.stl) | — | HD set |
| #110-001 | Base Mount Bottom | 1 | [`110-001_BaseMountBottom.stl`](../Hardware/Models/100-Base/110-001_BaseMountBottom.stl) | `HDI-110-001_BaseMountBottom` | HD set |
| #110-002 | Base Stator Holder | 1 | [`110-002_BaseStatorHolder.scad`](../Hardware/Models/100-Base/110-002_BaseStatorHolder.scad) | — | HD set; `config="revised"` seats the C-201 spline |
| #120-001 | Base Long | 1 | [`120-001_BaseLong.stl`](../Hardware/Models/100-Base/120-001_BaseLong.stl) | `HDI-220-001_BaseLong` | HD set |

**Print the three Stator Holders — `#110-002`, `#200-002` and `#511-002` — from `config="revised"`.** It
seats [C-201](007.1-Parts-Catalog.md#c-201--521-strain-wave-component-set)'s circular spline.
`config="previous"` is the HD mesh unchanged, drawn for a different spline, and is not printed. Those
meshes are kept in [`Hardware/Models/Reference/meshes/`](../Hardware/Models/Reference/meshes/).

### Arm body and belt directors — [007.5](007-Bill-of-Materials.md#0075-arm-body)

| PBS # | Part | Qty | Model | CAD ID | Source |
|---|---|---|---|---|---|
| #200-001 | Arm Body | 1 | [`200-001_ArmBody.stl`](../Hardware/Models/200-ArmBody/200-001_ArmBody.stl) | `HDI-310-001_ArmBody` | HD set |
| #200-002 | Pivot Stator Holder | 1 | [`200-002_PivotStatorHolder.scad`](../Hardware/Models/200-ArmBody/200-002_PivotStatorHolder.scad) | `HDI-311-006B_J2StatorHolder_ConeDrive` | HD set / GLTF; `config="revised"` seats the C-201 spline |
| #200-003 | Stator Balancer | **4** | [`200-003_StatorBalancer.stl`](../Hardware/Models/200-ArmBody/200-003_StatorBalancer.stl) | — | HD set |
| #200-006 | Calibration Arrows | 2 | [`200-006_CalibrationArrows.stl`](../Hardware/Models/200-ArmBody/200-006_CalibrationArrows.stl) | — | HD set |
| #210-001 | Belt Director Caps | 3 | [`210-001_IdlerPlug.stl`](../Hardware/Models/200-ArmBody/210-001_IdlerPlug.stl) | — | HD set |
| #210-002 | Belt Director Pulley | 1 | [`210-002_BeltDirectorPulley.stl`](../Hardware/Models/200-ArmBody/210-002_BeltDirectorPulley.stl) | — | HD set |
| #210-003 | Idler Plug | 1 | [`210-001_IdlerPlug.stl`](../Hardware/Models/200-ArmBody/210-001_IdlerPlug.stl) | — | HD set |
| #210-004 | Small Belt Director | 2 | [`210-004_SmallBeltDirector.stl`](../Hardware/Models/200-ArmBody/210-004_SmallBeltDirector.stl) | — | HD set |
| #210-005 | Large Belt Director | 1 | [`210-005_LargeBeltDirector.stl`](../Hardware/Models/200-ArmBody/210-005_LargeBeltDirector.stl) | — | HD set |

**Stator Balancers are fragile** — [008.5](008-Assembly.md) seats them with light mallet taps. Print
spares.

**#210-004/#210-005 are printed idler shafts, not bearing housings.** Each is a plain shouldered sleeve —
a Ø11.000 × 0.5 mm locating head on a Ø8.000 shank, 17.000 mm on the Small and 27.000 mm on the Large, cored
by a Ø4.700 blind bore from the open end. **The Ø8.000 shank is the MR128 bore**, so the two bearings on each
body go *onto* the shank and their Ø12 outer races carry the belt ([008.5](008-Assembly.md#0085-arm-body)
step 8). Six bearings over three bodies is [007.5](007-Bill-of-Materials.md#0075-arm-body)'s `#620-002`
quantity exactly. The head is 0.5 mm, which is what sets the layer height ceiling in
[Material](#material).

### Main pivot and motor end caps — [007.3](007-Bill-of-Materials.md#0073-harmonic-drive-motors), [007.4](007-Bill-of-Materials.md#0074-main-pivot)

| PBS # | Part | Qty | Model | CAD ID | Source |
|---|---|---|---|---|---|
| #300-001 | Main Pivot | 1 | [`300-001_MainPivot.stl`](../Hardware/Models/300-Pivot/300-001_MainPivot.stl) | `HDI-210-001_MainPivot` | HD set |
| #300-002 | Pivot Code Disk | 1 | [`300-002_PivotCodeDisk.stl`](../Hardware/Models/300-Pivot/300-002_PivotCodeDisk.stl) | — | HD set |
| #311-001 | Motor End Cap (Base) | 1 | [`311-001_MotorEndCapBase.stl`](../Hardware/Models/300-Pivot/311-001_MotorEndCapBase.stl) | — | HD set |
| #312-001 | Motor End Cap (Pivot) | 1 | [`312-001_MotorEndCapPivot.stl`](../Hardware/Models/300-Pivot/312-001_MotorEndCapPivot.stl) | — | HD set |

### Strain-wave drive adapters — [007.3](007-Bill-of-Materials.md#0073-harmonic-drive-motors), [007.8](007-Bill-of-Materials.md#0078-external-gear)

Three sets, one per strain-wave drive (J1 base, J2 pivot, J3 elbow).

| PBS # | Part | Qty | Model | CAD ID | Source |
|---|---|---|---|---|---|
| #630-004 | Wave Gen Coupler | **3** | [`630-004_WaveGenCoupler.stl`](../Hardware/Models/600-StrainWave/630-004_WaveGenCoupler.stl) | — | HD set |
| #630-005 | Flex Spline Attach | **3** | [`630-005_FlexSplineAttach.scad`](../Hardware/Models/600-StrainWave/630-005_FlexSplineAttach.scad) | — | HD set; `config="revised"` removes the flare below the land and seats the C-201 flexspline hub, and J3's also lowers the hub face by `hub_drop` |
| #630-006 | Flex Spline Cap | **3** | [`630-006_FlexSplineCap.scad`](../Hardware/Models/600-StrainWave/630-006_FlexSplineCap.scad) | — | HD set; `config="revised"` clamps the C-201 flexspline hub |

**Print the Flex Spline Attach and the Flex Spline Cap from `config="revised"`**: the Attach for J1 and J2
at the default `hub_drop` of 0, and for J3 at the drop [008.3](008-Assembly.md#0083-harmonic-drive-motors)
takes from its motor. `config="previous"` is the HD mesh unchanged, and is not printed. Those meshes are
kept in [`Hardware/Models/Reference/meshes/600-StrainWave/`](../Hardware/Models/Reference/meshes/600-StrainWave/).

**These parts are cut to the [C-201](007.1-Parts-Catalog.md#c-201--521-strain-wave-component-set) component
set**, whose mating dimensions are stated there and match this STL set. The Wave Gen Coupler is reamed
onto the motor shaft and lubricated on assembly ([008.3](008-Assembly.md)); the stator interfaces are the
Cone Drive variant. The set is on order (9–12 week lead time,
[DC-1](009-Design-Completion.md#strain-wave-component-set)); confirm it is in hand before printing the
final adapters, in case a physically received unit differs from the drawing.

### End arm hub and pulleys — [007.7](007-Bill-of-Materials.md#0077-end-arm-hub)

| PBS # | Part | Qty | Model | CAD ID | Source |
|---|---|---|---|---|---|
| #410-001 | Axis Intersection Half | 2 | [`410-001_AxisIntersectionHalf.stl`](../Hardware/Models/400-EndArm/410-001_AxisIntersectionHalf.stl) | — | HD set |
| #410-002 | New Belt Pulley | 1 | [`410-002_NewBeltPulley.stl`](../Hardware/Models/400-EndArm/410-002_NewBeltPulley.stl) | — | HD set |
| #410-003 | End Arm Code Disk | 1 | [`410-003_EndArmCodeDisk.stl`](../Hardware/Models/400-EndArm/410-003_EndArmCodeDisk.stl) | — | HD set |
| #420-001 | End Arm Hub | 1 | [`420-001_EndArmHub.stl`](../Hardware/Models/400-EndArm/420-001_EndArmHub.stl) | `HDI-500-001_EndArmHub` | HD set |
| #420-002 | End Arm Hub Cap | 1 | [`420-002_EndArmHubCap.stl`](../Hardware/Models/400-EndArm/420-002_EndArmHubCap.stl) | — | HD set |
| #421-001 | Internal Outer Pulley | 1 | [`421-001_InternalOuterPulley.stl`](../Hardware/Models/400-EndArm/421-001_InternalOuterPulley.stl) | — | HD set — **40T**, unchanged |
| #421-002 | Internal Inner Pulley | 1 | [`421-002_InternalInnerPulley.stl`](../Hardware/Models/400-EndArm/421-002_InternalInnerPulley.stl) | — | HD set — **40T**, unchanged |
| #421-006 | Pulley Spacer | 2 | [`421-006_PulleySpacer.stl`](../Hardware/Models/400-EndArm/421-006_PulleySpacer.stl) | — | HD set |
| #430-001 | External Outer Pulley | 1 | [`430-001_ExternalOuterPulley.scad`](../Hardware/Models/400-EndArm/430-001_ExternalOuterPulley.scad) | — | HD set, re-cut to **108T** in `config="revised"` |
| #430-002 | External Inner Pulley | 1 | [`430-002_ExternalInnerPulley.scad`](../Hardware/Models/400-EndArm/430-002_ExternalInnerPulley.scad) | — | HD set, re-cut to **108T** in `config="revised"` |

**Print the two External pulleys from `config="revised"`.** Each `.scad` keeps its HD mesh's hub and
adds a 108T rim ([DC-12](009-Design-Completion.md#wrist-pulley-rework)); `config="previous"` is that mesh
unchanged, 90T, and is not printed. The HD meshes are kept in
[`Hardware/Models/Reference/meshes/400-EndArm/`](../Hardware/Models/Reference/meshes/400-EndArm/). The
Internal pair is printed as modelled: 40T is the count
[004 § Wrist](004-Mechanical-Architecture.md#wrist-and-differential-j4j5) holds fixed.

### External gear and mount — [007.8](007-Bill-of-Materials.md#0078-external-gear), [007.9](007-Bill-of-Materials.md#0079-external-gear-mount--differential-motors)

| PBS # | Part | Qty | Model | CAD ID | Source |
|---|---|---|---|---|---|
| #510-001 | External Gear | 1 | [`510-001_ExternalGear.stl`](../Hardware/Models/500-ExternalGear/510-001_ExternalGear.stl) | — | HD set |
| #511-001 | Ex Gear Motor End Cap | 1 | [`511-001_ExGearMotorEndCap.scad`](../Hardware/Models/500-ExternalGear/511-001_ExGearMotorEndCap.scad) | — | HD set; `config="revised"` deepens the motor seat |
| #511-002 | Ex Gear Stator Holder | 1 | [`511-002_ExGearStatorHolder.scad`](../Hardware/Models/500-ExternalGear/511-002_ExGearStatorHolder.scad) | — | HD set; `config="revised"` seats the C-201 spline, its floor lowered to close J3's stack |
| #520-001 | Ex Gear Mount | 1 | [`520-001_ExGearMount.stl`](../Hardware/Models/500-ExternalGear/520-001_ExGearMount.stl) | `HDI-320-001_ExGearMount` | HD set |
| #520-002 | Ex Gear Mount Top | 1 | [`520-002_ExGearMountTop.stl`](../Hardware/Models/500-ExternalGear/520-002_ExGearMountTop.stl) | — | HD set |
| #520-003 | Nut Holder A | 1 | [`520-003_ExGearNutHold.stl`](../Hardware/Models/500-ExternalGear/520-003_ExGearNutHold.stl) | — | HD set |
| #520-004 | Nut Holder B | 1 | [`520-003_ExGearNutHold.stl`](../Hardware/Models/500-ExternalGear/520-003_ExGearNutHold.stl) | — | HD set |

**Print the Ex Gear Motor End Cap from `config="revised"`.** `config="previous"` is the HD mesh
unchanged, and is not printed. That mesh is kept in
[`Hardware/Models/Reference/meshes/500-ExternalGear/`](../Hardware/Models/Reference/meshes/500-ExternalGear/).

### Differential — [007.6](007-Bill-of-Materials.md#0076-differential)

This group has full **parametric OpenSCAD source** in
[`Hardware/Models/700-Differential/`](../Hardware/Models/700-Differential/), and nothing else: the `.scad`
is the source of record, `render.rs --meshes` writes the printable meshes to an untracked `out/`, and each
part's original mesh is kept only as what that render is gated against, in
[`Hardware/Models/Reference/meshes/700-Differential/`](../Hardware/Models/Reference/meshes/700-Differential/)
([`Hardware/Models/README.md`](../Hardware/Models/README.md#moving-to-openscad)).

| PBS # | Part | Qty | Model | Source |
|---|---|---|---|---|
| #710-001 | Split Gear Top | 1 | [`710-001_SplitGearTop.scad`](../Hardware/Models/700-Differential/710-001_SplitGearTop.scad) | Authored parametrically |
| #710-002 | Split Gear Bottom | 1 | [`710-002_SplitGearBottom.scad`](../Hardware/Models/700-Differential/710-002_SplitGearBottom.scad) | Authored parametrically |
| #710-003 | Diff Keeper | 2 | [`710-003_DiffKeeper.scad`](../Hardware/Models/700-Differential/710-003_DiffKeeper.scad) | Authored parametrically |
| #710-004 | Rotate Code Disk | 1 | [`710-004_RotateCodeDisk.scad`](../Hardware/Models/700-Differential/710-004_RotateCodeDisk.scad) | Authored parametrically |
| #720-001 | Diff Gear Shaft | 1 | [`720-001_DiffGearShaft.scad`](../Hardware/Models/700-Differential/720-001_DiffGearShaft.scad) | Authored parametrically |
| #720-002 | Diff Gear Axle | 1 | [`720-002_DiffGearAxle.scad`](../Hardware/Models/700-Differential/720-002_DiffGearAxle.scad) | Authored parametrically |
| #720-003 | Diff End Pulley | 1 | [`720-003_DiffEndPulley.scad`](../Hardware/Models/700-Differential/720-003_DiffEndPulley.scad) | Authored parametrically |
| #720-004 | Diff Shaft Pulley | 1 | [`720-004_DiffShaftPulley.scad`](../Hardware/Models/700-Differential/720-004_DiffShaftPulley.scad) | Authored parametrically; `config="revised"` only |
| #730-001 | Diff Body A | 1 | [`730-001_DiffBodyA.scad`](../Hardware/Models/700-Differential/730-001_DiffBodyA.scad) | Authored parametrically |
| #730-002 | Diff Body B | 1 | [`730-002_DiffBodyB.scad`](../Hardware/Models/700-Differential/730-002_DiffBodyB.scad) | Authored parametrically |

Print `config="revised"`, the model set's default
([004](004-Mechanical-Architecture.md#wrist-and-differential-j4j5)). It carries
the 80T inputs and fits the HDI-940 covers; `config="previous"` reproduces the previous version's
differential at 40T, which does not match `AxisCal`
([DC-12](009-Design-Completion.md#wrist-pulley-rework)), and is kept as the reference the renders are
gated against. The revised configuration is unproven on a physical build until the DC-9 checklist
passes.

**`#720-001` prints solid.** Print it with `wall_holes = false`, which is the file's default. The wall holes
that flag reproduces are in the reference mesh, but they cannot be built and no part uses them
([`Hardware/Models/README.md`](../Hardware/Models/README.md#verifying-a-recreated-part-against-its-reference)).
The `true` state is only for comparing the model against its reference.

**`710-002_SplitGearBottom.stl` scale defect — resolved.** The shipped file was exactly 1000× oversize;
the corrected, mate-verified STL is committed and the closure evidence (factor, checks, hashes) is in
[DC-11(f)](009-Design-Completion.md#procurement-data).

### Wire harness — [007.10](007-Bill-of-Materials.md#00710-wire-harness)

| PBS # | Part | Qty | Model | CAD ID | Source |
|---|---|---|---|---|---|
| #800-001 | Wire Entry Left | 1 | [`800-001_WireEntryLeft.stl`](../Hardware/Models/800-Harness/800-001_WireEntryLeft.stl) | — | HD set |
| #800-002 | Wire Entry Right | 1 | [`800-002_WireEntryRight.stl`](../Hardware/Models/800-Harness/800-002_WireEntryRight.stl) | — | HD set |
| #800-003 | Main Pivot Plug A | 1 | [`800-003_MainPivotPlugA.stl`](../Hardware/Models/800-Harness/800-003_MainPivotPlugA.stl) | — | HD set |
| #800-004 | Main Pivot Plug B | 1 | [`800-004_MainPivotPlugB.stl`](../Hardware/Models/800-Harness/800-004_MainPivotPlugB.stl) | — | HD set |
| #800-005 | Fan Bracket | 1 | [`800-005_FanBracket.stl`](../Hardware/Models/800-Harness/800-005_FanBracket.stl) | `HDI-730-005_Fan` (fan body) | HD set |
| #800-006 | PCB Bracket | 2 | [`800-006_PCBBracket.stl`](../Hardware/Models/800-Harness/800-006_PCBBracket.stl) | — | HD set |
| #800-007 | PCB Spacer | **4** | [`800-007_PCBSpacer.stl`](../Hardware/Models/800-Harness/800-007_PCBSpacer.stl) | — | HD set |
| #810-001 | 6-pin strain relief, top | **10** | [`810-001_6PinStrainReliefTop.stl`](../Hardware/Models/800-Harness/810-001_6PinStrainReliefTop.stl) | — | HD set |
| #810-002 | 6-pin strain relief, bottom | **10** | [`810-002_6PinStrainReliefBottom.stl`](../Hardware/Models/800-Harness/810-002_6PinStrainReliefBottom.stl) | — | HD set |
| #821 | Photointerrupter shroud — base | 1 | [`821_PhotointerrupterShroudBase_A.stl`](../Hardware/Models/800-Harness/821_PhotointerrupterShroudBase_A.stl) | — | HD set |
| #822 | Photointerrupter shroud — pivot | 1 | [`822_PhotointerrupterShroudPivot_A.stl`](../Hardware/Models/800-Harness/822_PhotointerrupterShroudPivot_A.stl) | — | HD set |
| #823 | Photointerrupter shroud — end arm | 1 | [`823_PhotointerrupterShroudEndArm.stl`](../Hardware/Models/800-Harness/823_PhotointerrupterShroudEndArm.stl) | — | HD set |
| #824 | Photointerrupter shroud — angle | 1 | [`824_PhotointerrupterShroudAngle.stl`](../Hardware/Models/800-Harness/824_PhotointerrupterShroudAngle.stl) | — | HD set |
| #825 | Photointerrupter shroud — rotate | 1 | [`825_PhotointerrupterShroudRotate_A.stl`](../Hardware/Models/800-Harness/825_PhotointerrupterShroudRotate_A.stl) | — | HD set |

[007.10](007-Bill-of-Materials.md#00710-wire-harness) quotes the strain reliefs as "as needed" and the
shrouds as "per joint". **Resolved here as 10 pairs of strain relief** (one per
[C-708](007.1-Parts-Catalog.md#7-electronics-and-wiring) 6-pin connector) **and one shroud per joint**
(5 joints, five distinct geometries). Print spares of both — they are small and consumed by rework.
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

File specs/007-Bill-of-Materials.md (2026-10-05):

# 007 — Bill of Materials

This document lists the parts that realize the mechanical architecture ([004](004-Mechanical-Architecture.md))
and electronics ([005](005-Electronics-and-Control.md)). It is a **derived artifact**: when the design
changes, regenerate this list. Parts are organized by subassembly; subassembly numbers match the assembly
steps in [008-Assembly.md](008-Assembly.md). Legacy Product Breakdown Structure (PBS) part numbers are
retained in the `PBS #` column for traceability to the source parts library.

Open design items are cross-referenced to
[009-Design-Completion.md](009-Design-Completion.md). Order fasteners and bearings in excess — the aggregate
totals below carry no slack, and several rows depend on [009](009-Design-Completion.md) items being finalized.

**To order or fabricate parts, use the derived lists rather than this document** —
[007.1](007.1-Parts-Catalog.md) for anything purchased or fabricated,
[007.2](007.2-Printed-Parts.md) for anything printed. Both are de-duplicated across the whole robot, where
this document counts a part once per subassembly that consumes it. This document is the by-subassembly view
and the source those two are generated from; each carries its own regeneration procedure.

## Subassembly summary

| # | Subassembly | PBS | Open item |
|---|---|---|---|
| [007.1](#0071-glue-rig-assembly) | Glue Rig (tooling) | F | — |
| [007.2](#0072-base) | Base | A | — |
| [007.3](#0073-harmonic-drive-motors) | Harmonic Drive Motors (J1, J2) | D | — |
| [007.4](#0074-main-pivot) | Main Pivot (J2) | C | — |
| [007.5](#0075-arm-body) | Arm Body (L2) | B | — |
| [007.6](#0076-differential) | Differential (J4/J5) | H | — |
| [007.7](#0077-end-arm-hub) | End Arm Hub (L3) | E | — |
| [007.8](#0078-external-gear) | External Gear (J3 drive) | G | — |
| [007.9](#0079-external-gear-mount--differential-motors) | Ex Gear Mount + Diff Motors (J4/J5) | I | — |
| [007.10](#00710-wire-harness) | Wire Harness | J | [DC-7](009-Design-Completion.md#motor-control-pcb) |
| [007.11](#00711-tool-interface--gripper) | Tool Interface / Gripper | K–O | — |

## Strain-wave component set (applies to 007.3 and 007.8)

Each of the three 52:1 drives (J1, J2, J3) takes one component set
([004](004-Mechanical-Architecture.md#base-joints-j1j3-strain-wave-drive)), so **nine special-order parts**
are needed in all. Confirmed as three
**HanZhen `XB1-AS-C-32(14)-52`** sets, USD 120 each
([C-201](007.1-Parts-Catalog.md#c-201--521-strain-wave-component-set)). **Order this first:** it carries the
longest lead time in the build (9–12 weeks).

---

## 007.1 Glue Rig Assembly
The glue rigs are **tooling** — printed jigs that hold each bonded span at its finished spacing while the
epoxy cures. They add **nothing** to this bill: the parts they hold are the robot's own, counted in their
own subassemblies below, and the jigs themselves are printed parts listed in
[007.2 § Tooling](007.2-Printed-Parts.md#tooling--glue-rigs), which also records the span each rig bonds.

## 007.2 Base
Realizes the bolted base ([004](004-Mechanical-Architecture.md#base-j1)).

| PBS # | Part | Type | Qty | Notes |
|---|---|---|---|---|
| #100-001 | Base Clamp | 3D print | 1 | One clamp; seat and stack per [004 § Base mounting plate](004-Mechanical-Architecture.md#base-mounting-plate) |
| #100-002 | Base Code Disc | 3D print | 1 | |
| #100-003 | Pivot Skirt | 3D print | 1 | |
| #110-001 | Base Mount Bottom | 3D print | 1 | |
| #110-002 | Base Stator Holder | 3D print | 1 | |
| #110-003 | 133 × 12.6 × 3.2 mm CF strake | Fabricate | 3 | Cut from [C-501](007.1-Parts-Catalog.md#c-501--carbon-fibre-strip-125--500) — .125″ × .500″ stock |
| #110-004 | **Base Mounting Plate** | Machine (metal) | 1 | Material, thickness, footprint, and hole patterns per [004 § Base mounting plate](004-Mechanical-Architecture.md#base-mounting-plate). Cut from [`110-004_BaseMountingPlate.scad`](../Hardware/Models/100-Base/110-004_BaseMountingPlate.scad) |
| — | M6 bolt + 2 washers + nut (plate to work surface) | Off the shelf | 4 sets | Class 8.8 or better; length and the T-slot clamp alternative are in [004](004-Mechanical-Architecture.md#base-mounting-plate) |
| — | M6 × 18 mm socket head cap screw (Base Mount Bottom to plate) | Off the shelf | **8** | Driven from inside the base into the plate's tapped holes; head seats in the flange counterbore, so no washer is used |
| #120-001 | Base Long | 3D print | 1 | |
| #120-002 | 133 × 12.6 × 3.2 mm CF strake | Fabricate | 3 | Cut from [C-501](007.1-Parts-Catalog.md#c-501--carbon-fibre-strip-125--500) — .125″ × .500″ stock |
| #120-003 | 107 mm M3 all-thread | Fabricate | 3 | |
| #620-006 | 6810 bearing | Off the shelf | 1 | The Base Long's lower bore ([008.4](008-Assembly.md#0084-main-pivot) step 9a). Its upper bore takes the Base Motor End Cap's bearing, counted in [007.3](#0073-harmonic-drive-motors) |
| #660-002 | M3 nuts | Off the shelf | **8** | 7, plus one for the clamp |
| #642-004 | M3 × 20 mm socket head screw | Off the shelf | 1 | The clamp bolt — see [004 § Base mounting plate](004-Mechanical-Architecture.md#base-mounting-plate) |
| #670-003 | #6 washers | Off the shelf | 3 | |

*(The previous version's #111-001 Foot ×6 and #111-002 aluminium strake ×6 do not appear in this design;
the Base Mounting Plate takes their place.)*

## 007.3 Harmonic Drive Motors
Builds the **base (J1)** and **pivot (J2)** motor assemblies — 2 of the 3 strain-wave drives (the 3rd is in
[007.8](#0078-external-gear)). Quantities are **per motor** (×2).

| PBS # | Part | Type | Qty (per motor) | Notes |
|---|---|---|---|---|
| #311-001 / #312-001 | Motor End Cap (Base / Pivot) | 3D print | 1 | |
| #610-001 | NEMA-17 stepper, 0.9°/step | Off the shelf | 1 | |
| #620-006 | 6810 bearing | Off the shelf | 1 | |
| #630-001 | **Flex Spline** | Special order | 1 | Part of the strain-wave component set — [C-201](007.1-Parts-Catalog.md#c-201--521-strain-wave-component-set) |
| #630-002 | **Wave Generator** | Special order | 1 | Part of the strain-wave component set — [C-201](007.1-Parts-Catalog.md#c-201--521-strain-wave-component-set) |
| #630-003 | **Stator Gear** | Special order | 1 | Part of the strain-wave component set — [C-201](007.1-Parts-Catalog.md#c-201--521-strain-wave-component-set) |
| #630-004 | Wave Gen Coupler | 3D print | 1 | |
| #630-005 | Flex Spline Attach | 3D print | 1 | |
| #630-006 | Flex Spline Cap | 3D print | 1 | |
| #641-002 | M2 × 12 mm bolts | Off the shelf | 6 | |
| #641-003 | M2 × 20 mm bolts | Off the shelf | 4 | |
| #642-003 | M3 × 12 mm socket head screws | Off the shelf | 10 | 4 Attach, 6 circular spline |
| #642-006 | M3 × 8 mm hex cap bolt | Off the shelf | 2 | |
| #660-001 | M2 nuts | Off the shelf | 10 | |
| #660-002 | M3 nuts | Off the shelf | 6 | Circular spline, in the Stator Holder |
| #670-001 | M2 washers | Off the shelf | 4 | |
| #670-003 | #6 washers | Off the shelf | 4 | |

## 007.4 Main Pivot
J2 shoulder structure ([004](004-Mechanical-Architecture.md#main-pivot-j2-and-arm-body-j3-support--l2)).

| PBS # | Part | Type | Qty | Notes |
|---|---|---|---|---|
| #300-001 | Main Pivot (printed body) | 3D print | 1 | |
| #300-002 | Pivot Code Disk | 3D print | 1 | |
| #300-003 | 126 × 12.6 × 3.2 mm CF strake | Fabricate | 4 | Cut from [C-501](007.1-Parts-Catalog.md#c-501--carbon-fibre-strip-125--500) — .125″ × .500″ stock. Unchanged in length — these are bonded stiffeners and set no link length. L1 is set by the base stack in [004 § Base mounting plate](004-Mechanical-Architecture.md#base-mounting-plate) |
| #300-004 | 146 × 12.6 × 3.2 mm CF strake | Fabricate | 4 | Cut from [C-501](007.1-Parts-Catalog.md#c-501--carbon-fibre-strip-125--500) — .125″ × .500″ stock |
| #660-002 | M3 nuts | Off the shelf | 5 | |

Also consumes the two motor assemblies from [007.3](#0073-harmonic-drive-motors), and the Base Long's 6810
bearing and the Base Code Disk / Base Stator Holder from [007.2](#0072-base) — see
[008.4](008-Assembly.md#0084-main-pivot).

## 007.5 Arm Body
L2 span (J2→J3) plus belt-director sub-unit. The L2 tube length is specific to this version.

| PBS # | Part | Type | Qty | Notes |
|---|---|---|---|---|
| #200-001 | Arm Body (printed) | 3D print | 1 | Bonded in a glue rig ([007.1](#0071-glue-rig-assembly)) |
| #200-002 | Pivot Stator Holder | 3D print | 1 | |
| #200-003 | Stator Balancer | 3D print | 4 | |
| #200-005 | 1" CF square tube | Fabricate | 1 | **Cut length 264.0 mm.** This span is L2 ([C-504](007.1-Parts-Catalog.md#c-504--braided-carbon-fibre-square-tube-1)) |
| #200-006 | Calibration Arrows | 3D print | 2 | |
| #620-006 | 6810 bearing | Off the shelf | 1 | |
| #210-001 | Belt Director Caps | 3D print | 3 | |
| #210-002 | Belt Director Pulley | 3D print | 1 | |
| #210-003 | Idler Plug | 3D print | 1 | |
| #210-004 | Small Belt Director | 3D print | 2 | |
| #210-005 | Large Belt Director | 3D print | 1 | |
| #620-001 | MR85 bearing | Off the shelf | 1 | |
| #620-002 | MR128 bearing | Off the shelf | 6 | |
| #641-003 | M2 × 20 mm bolt | Off the shelf | 1 | |
| #660-001 | M2 nut | Off the shelf | 1 | |
| #670-001 | M2 washer | Off the shelf | 1 | |

The belt directors sit in the J4/J5 drive path and are **idlers**: `#210-002` measures as a **26T GT2**
toothed pulley (tip Ø 15.92, root Ø 14.61 — the same ≈0.13 mm under-standard tip as every other printed
pulley in the set), and [008.5](008-Assembly.md) mounts it on an *idler plug* rather than a shaft. It
engages the belt teeth to route the belt and **contributes no reduction**, because an idler in a single
belt path passes the same belt from driver to driven whatever its own count. The net 13.5:1 and the tooth
counts that realize it are specified in [004 § Wrist](004-Mechanical-Architecture.md#wrist-and-differential-j4j5). Verify wrist
resolution empirically after build.

## 007.6 Differential
J4/J5 wrist ([004](004-Mechanical-Architecture.md#wrist-and-differential-j4j5)). This
parts list realizes the previous version's differential, built as a working substitute per
[004 § Wrist and differential](004-Mechanical-Architecture.md#wrist-and-differential-j4j5).

| PBS # | Part | Type | Qty | Notes |
|---|---|---|---|---|
| #710-001 | Split Gear Top | 3D print | 1 | The dimensional datum for checking `#710-002` |
| #710-002 | Split Gear Bottom | 3D print | 1 | Former scale defect resolved — corrected STL and parametric source committed ([DC-11(f)](009-Design-Completion.md#procurement-data)) |
| #710-003 | Diff Keeper | 3D print | 2 | |
| #710-004 | Rotate Code Disk | 3D print | 1 | |
| #710-005 | 25 × 5.6 × 2.5 mm CF strake | Fabricate | 3 | Cut from [C-502](007.1-Parts-Catalog.md#c-502--carbon-fibre-strip-092--220) — .092″ × .220″ stock |
| #710-006 | AXK0819 thrust bearing (1/4") | Off the shelf | 1 | |
| #710-007 | AS thrust races | Off the shelf | 2 | |
| #720-001 | Diff Gear Shaft | 3D print | 1 | Its 40T band keys `#720-004` |
| #720-002 | Diff Gear Axle | 3D print | 1 | |
| #720-003 | Diff End Pulley | 3D print | 1 | **80T GT2** per [004 § Wrist](004-Mechanical-Architecture.md#wrist-and-differential-j4j5) |
| #720-004 | Diff Shaft Pulley | 3D print | 1 | **80T GT2** — the Diff Gear Shaft's input ([DC-12](009-Design-Completion.md#wrist-pulley-rework)) |
| #720-006 | 96 × 8 × 6 mm CF rod | Fabricate | 1 | |
| #730-001 | Diff Body A | 3D print | 1 | |
| #730-002 | Diff Body B | 3D print | 1 | |
| #620-001 | MR85 bearing | Off the shelf | 1 | Its **outer** race is the one that seats ([DC-11(e)](009-Design-Completion.md#procurement-data)) |
| #620-002 | MR128 bearing | Off the shelf | 4 | **Was 2.** Four Ø12 seats: both ends of `#720-001`, and one in each Split Gear half ([DC-11(e)](009-Design-Completion.md#procurement-data)) |
| #620-003 | 6703 bearing | Off the shelf | 6 | **Was 5.** Five Ø23 seats in this subassembly's own parts, and a sixth that [008.6](008-Assembly.md#0086-differential) step 2 presses into `#420-001` ([DC-11(e)](009-Design-Completion.md#procurement-data)) |
| #620-004 | 6705 bearing | Off the shelf | 1 | |
| #642-005 | M3 × 6 mm set screws | Off the shelf | 3 | |
| #680-001 | 1" #19 finishing nail | Off the shelf | 4 | Locking dowels |

`#720-005`, five 60 × 4.4 × 1.5 mm CF strakes, is **withdrawn**: no part in this subassembly carries a slot
that would take one, and no step places them ([DC-11(e)](009-Design-Completion.md#procurement-data)).

Consumables: cyanoacrylate, hot glue, a small zip tie, epoxy.

## 007.7 End Arm Hub
L3 span (J3→J4), axis intersection, internal/external pulleys. The L3 tube length is
specific to this version.

| PBS # | Part | Type | Qty | Notes |
|---|---|---|---|---|
| #410-001 | Axis Intersection Half | 3D print | 2 | Bonded in a glue rig ([007.1](#0071-glue-rig-assembly)) |
| #410-002 | New Belt Pulley | 3D print | 1 | |
| #410-003 | End Arm Code Disk | 3D print | 1 | |
| #410-004 | 45 × 5.6 × 2.5 mm CF strake | Fabricate | 2 | Cut from [C-502](007.1-Parts-Catalog.md#c-502--carbon-fibre-strip-092--220) — .092″ × .220″ stock |
| #410-005 | 48 × 5.6 × 2.5 mm CF strake | Fabricate | 2 | Cut from [C-502](007.1-Parts-Catalog.md#c-502--carbon-fibre-strip-092--220) — .092″ × .220″ stock |
| #410-006 | M3 × 107 mm all-thread | Fabricate | 4 | |
| #420-001 | End Arm Hub (printed) | 3D print | 1 | Bonded in a glue rig ([007.1](#0071-glue-rig-assembly)) |
| #420-002 | End Arm Hub Cap | 3D print | 1 | |
| #420-003 | 0.75" CF square tube | Fabricate | 1 | **Cut length 243.0 mm.** This span is L3 ([C-505](007.1-Parts-Catalog.md#c-505--braided-carbon-fibre-square-tube-075)) |
| #421-001 | Internal Outer Pulley | 3D print | 1 | **40T GT2** — unchanged; the count [004 § Wrist](004-Mechanical-Architecture.md#wrist-and-differential-j4j5) holds fixed |
| #421-002 | Internal Inner Pulley | 3D print | 1 | **40T GT2** — unchanged. Its Ø17 6703 seat is the constraint that floors this count |
| #421-003 | 113 × 8 × 6 mm stainless steel rod | Fabricate | 1 | |
| #421-004 | 81 × 4.4 × 1.5 mm CF strake | Fabricate | 3 | Cut from [C-503](007.1-Parts-Catalog.md#c-503--carbon-fibre-strip-057--177) — .057″ × .177″ stock |
| #421-005 | 940 mm (470T) × 6 mm GT2 belt | Off the shelf | 2 | Stage 2, 40T → 80T. Was 90 cm at 40T → 40T; length derived in [007.1 § 3](007.1-Parts-Catalog.md#3-belts-and-pulleys) — confirm against the measured centre distance before ordering |
| #421-006 | Pulley Spacer | 3D print | 2 | |
| #430-001 | External Outer Pulley | 3D print | 1 | **108T GT2** per [004 § Wrist](004-Mechanical-Architecture.md#wrist-and-differential-j4j5) |
| #430-002 | External Inner Pulley | 3D print | 1 | **108T GT2**, as `#430-001` |
| #430-004 | 1140 mm (570T) × 6 mm GT2 belt | Off the shelf | 2 | Stage 1, 16T → 108T. Was 112 cm at 16T → 90T; length derived in [007.1 § 3](007.1-Parts-Catalog.md#3-belts-and-pulleys) — confirm against the measured centre distance before ordering |
| #620-002 | MR128 bearing | Off the shelf | 2 | |
| #620-003 | 6703 bearing | Off the shelf | 3 | |
| #620-005 | 6807 bearing | Off the shelf | 2 | |
| #620-001 | MR85 bearing | Off the shelf | 1 | |
| #642-005 | M3 × 6 mm set screws | Off the shelf | 6 | |
| #660-002 | M3 nuts | Off the shelf | 18 | |
| #670-002 | M3 washers | Off the shelf | 8 | |

## 007.8 External Gear
Builds the **3rd strain-wave drive (J3 elbow)** plus the external gear housing.

| PBS # | Part | Type | Qty | Notes |
|---|---|---|---|---|
| #510-001 | External Gear (printed) | 3D print | 1 | |
| #510-002 | 132 cm × 9 mm GT2 belt | Off the shelf | 2 | |
| #511-001 | Ex Gear Motor End Cap | 3D print | 1 | |
| #511-002 | Ex Gear Stator Holder | 3D print | 1 | |
| #511-003 | 73 × 12.6 × 3.2 mm CF strake | Fabricate | 3 | Cut from [C-501](007.1-Parts-Catalog.md#c-501--carbon-fibre-strip-125--500) — .125″ × .500″ stock |
| #610-001 | NEMA-17 stepper | Off the shelf | 1 | |
| #620-006 | 6810 bearing | Off the shelf | 2 | |
| #630-001/2/3 | **Flex Spline / Wave Generator / Stator Gear** | Special order | 1 each | Part of the strain-wave component set — [C-201](007.1-Parts-Catalog.md#c-201--521-strain-wave-component-set) |
| #630-004 | Wave Gen Coupler | 3D print | 1 | |
| #630-005 | Flex Spline Attach | 3D print | 1 | |
| #630-006 | Flex Spline Cap | 3D print | 1 | |
| #641-002 | M2 × 12 mm bolts | Off the shelf | 6 | |
| #641-003 | M2 × 20 mm bolts | Off the shelf | 4 | |
| #642-003 | M3 × 12 mm socket head screws | Off the shelf | 10 | 4 End Cap, 6 circular spline |
| #642-006 | M3 × 8 mm hex cap bolt | Off the shelf | 2 | |
| #660-001 | M2 nuts | Off the shelf | 10 | |
| #660-002 | M3 nuts | Off the shelf | 12 | 4 End Cap, 2 all-thread, 6 circular spline |
| #670-001 | M2 washers | Off the shelf | 4 | |
| #670-003 | #6 washers | Off the shelf | 4 | |

## 007.9 External Gear Mount + Differential Motors
Mounts the two plain **J4/J5 (angle + rotate) steppers** that drive the differential.

| PBS # | Part | Type | Qty | Notes |
|---|---|---|---|---|
| #520-001 | Ex Gear Mount (printed) | 3D print | 1 | Bonded in a glue rig ([007.1](#0071-glue-rig-assembly)) |
| #520-002 | Ex Gear Mount Top | 3D print | 1 | |
| #520-003 | Nut Holder A | 3D print | 1 | |
| #520-004 | Nut Holder B | 3D print | 1 | |
| #520-005 | M3 × 46 mm all-thread | Fabricate | 2 | |
| #520-006 | 1" × 68 mm CF square tube | Fabricate | 1 | Bonded in a glue rig ([007.1](#0071-glue-rig-assembly)) |
| #620-006 | 6810 bearing | Off the shelf | 1 | The Ex Gear Mount Top's seat ([008.8](008-Assembly.md#0088-external-gear) step 13) |
| #642-003 | M3 × 12 mm socket head screws | Off the shelf | 4 | |
| #660-002 | M3 nuts | Off the shelf | 4 | |
| #670-003 | #6 washers | Off the shelf | 2 | |
| #610-001 | NEMA-17 stepper (angle + rotate) | Off the shelf | 2 | Plain steppers, no strain-wave drive |
| #642-004 | M3 × 8 mm bolts | Off the shelf | 8 | |
| #670-002 | M3 washers | Off the shelf | 8 | |
| #6A0-001 | 16T × 5 mm GT2 pulley (motor) | Off the shelf | 2 | Motor pulley, retained. It drives the 108T External pulleys at 6.75:1 ([004 § Wrist](004-Mechanical-Architecture.md#wrist-and-differential-j4j5)) |
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

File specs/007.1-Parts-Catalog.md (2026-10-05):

# 007.1 — Parts Catalog and Sourcing

This document is the **de-duplicated purchase list for one complete robot**. Where
[007-Bill-of-Materials.md](007-Bill-of-Materials.md) lists parts *by subassembly* — so the same M3 nut
appears in six places — this document lists each distinct orderable item **exactly once**, with the full
product specification needed to order the correct item and at least one supplier link per part.

It is a **derived artifact**: it is generated from [007](007-Bill-of-Materials.md), which is itself derived
from the design in [004](004-Mechanical-Architecture.md)–[006](006-Firmware-and-Calibration.md). When the
design changes, regenerate both. The procedure is in
[Regenerating this catalog](#regenerating-this-catalog).

3D-printed parts are **not** listed here. They are in [007.2-Printed-Parts.md](007.2-Printed-Parts.md).

## How to use this catalog

**Order of operations.** Lead time, not cost, drives the sequence:
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

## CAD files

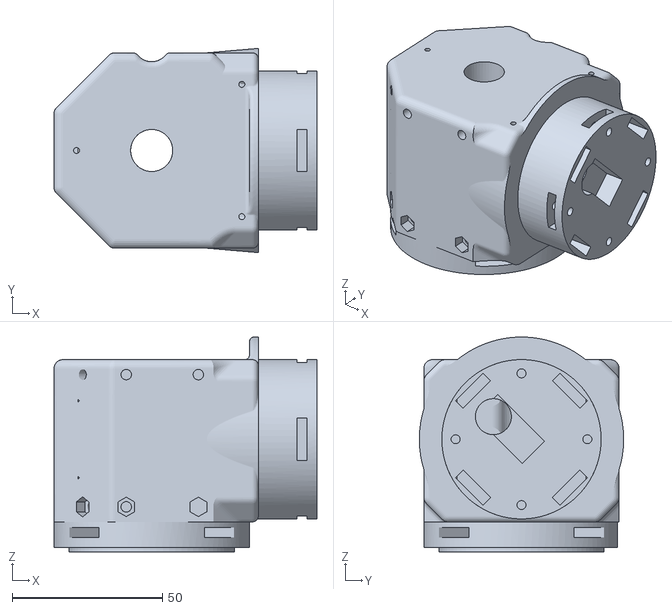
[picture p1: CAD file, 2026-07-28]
Hardware/Models/300-Pivot/300-001_MainPivot.stl
87.5 x 68.0 x 71.5

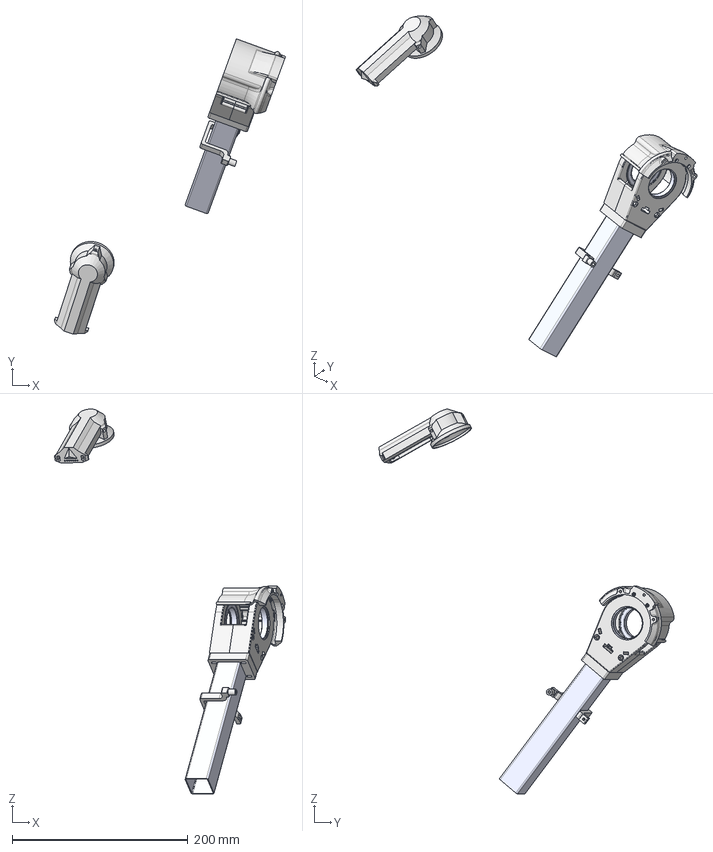
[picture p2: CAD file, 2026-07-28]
Hardware/Models/Reference/onshape-v1/assemblies/KA0006-01_Main_flattened.step
263.1 x 336.1 x 438.1 mm
M3-Nut_90591A250_ZINC PLATED STEEL HEX NUT x 6
KP0093-01_ToolInterface
KP0058-01_PCBBracket
KP0053-01_CompositeBarShoulder
KP0059-01_PCBSpacer
KP0047-01_AxisInterSectionHalfSM
KP0052-01_B6807ZZ_2_03 x 2
KP0048-01_AxisInterSectionHalfSM_B
KP0049-01_MainHubPhotoIntTRM
KP0046-01_1InTubeInterfaceB

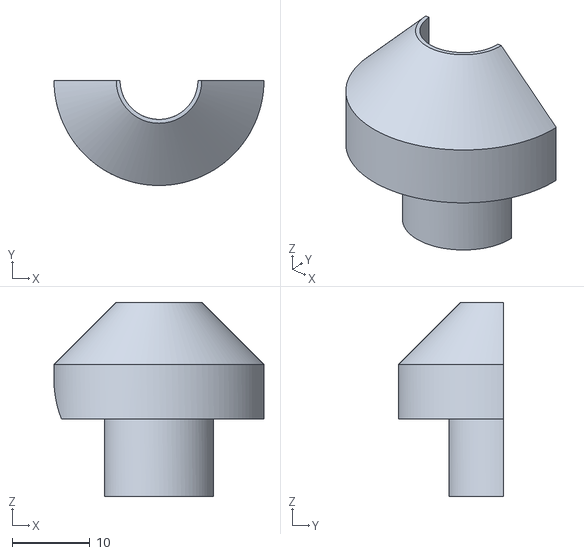
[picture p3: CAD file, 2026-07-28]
Hardware/Models/800-Harness/800-003_MainPivotPlugA.stl
27.0 x 13.5 x 25.0

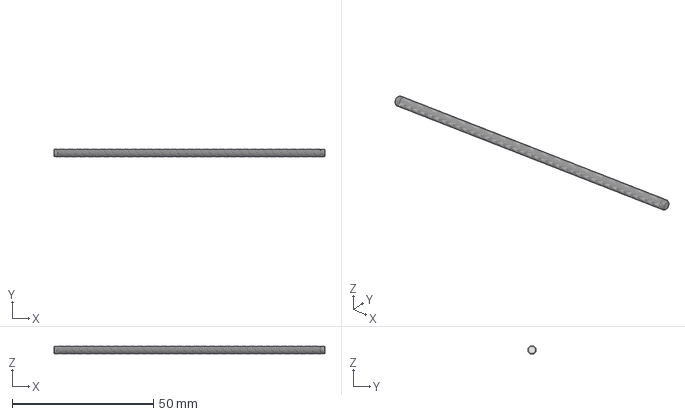
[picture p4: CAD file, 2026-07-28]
Hardware/Models/Reference/onshape-v1/parts-step/KP0011-01_M3 96 LOW-STRENGTH STEEL FULLY THREADED STUD.step
96.0 x 3.00 x 3.00 mm

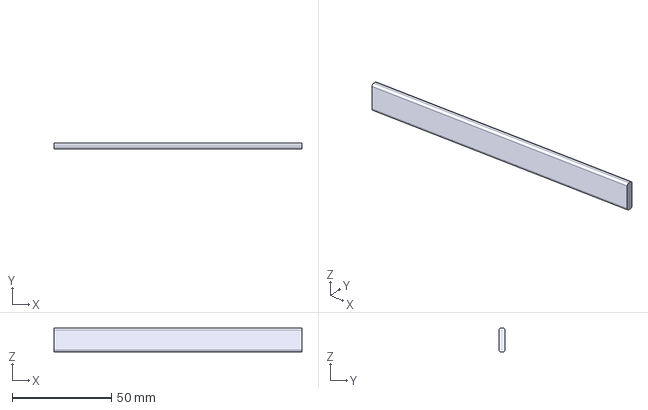
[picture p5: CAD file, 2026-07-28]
Hardware/Models/Reference/onshape-v1/parts-step/KP0025-01_MainPivotBar.step
125.0 x 3.00 x 12.0 mm

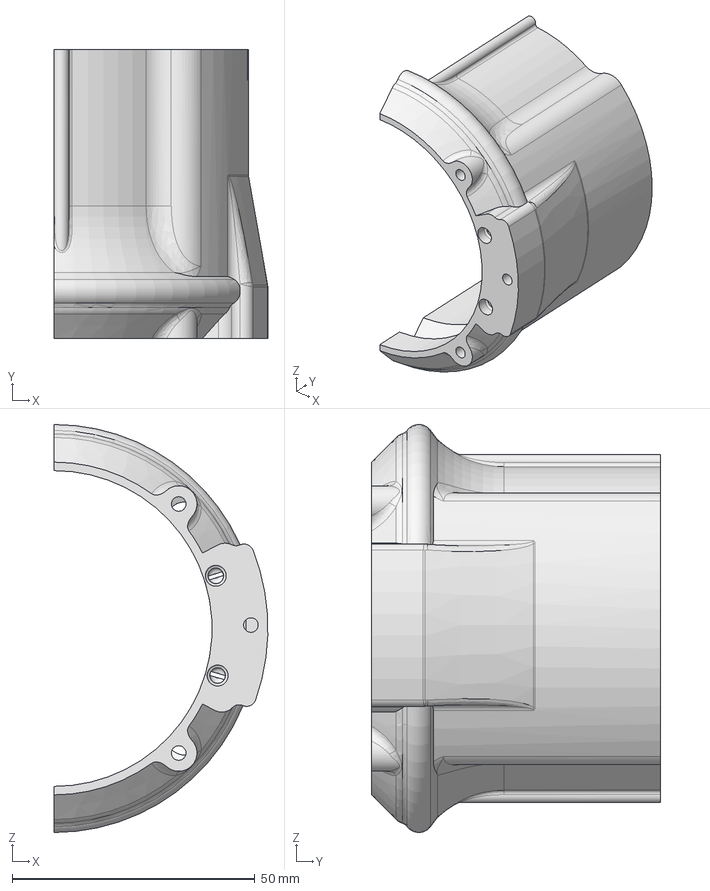
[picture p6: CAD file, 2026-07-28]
Hardware/Models/Reference/onshape-v1/parts-step/KP0049-01_MainHubPhotoIntTRM.step
44.0 x 59.5 x 84.0 mm

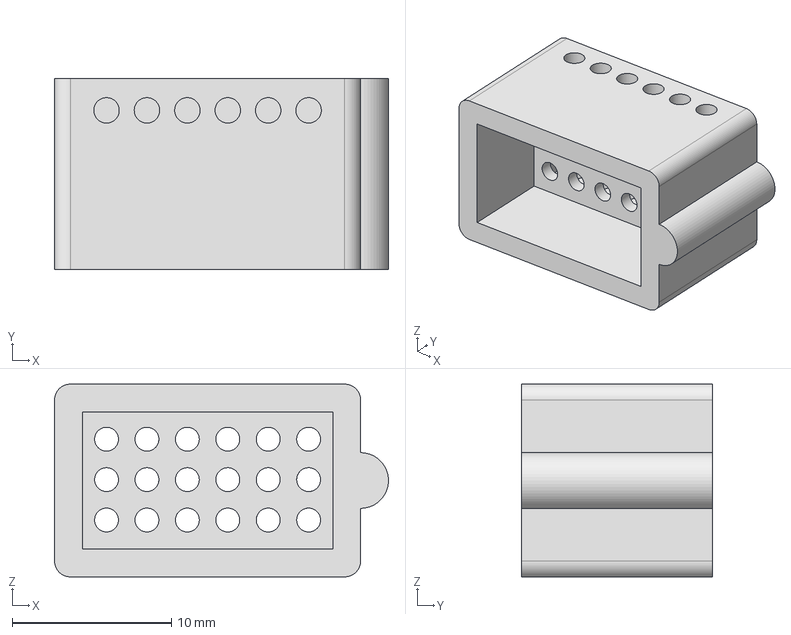
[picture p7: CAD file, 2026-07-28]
Hardware/Models/Reference/onshape-v1/parts-step/KP0044-01_MainESocketFemSM.step
21.0 x 12.0 x 12.1 mm

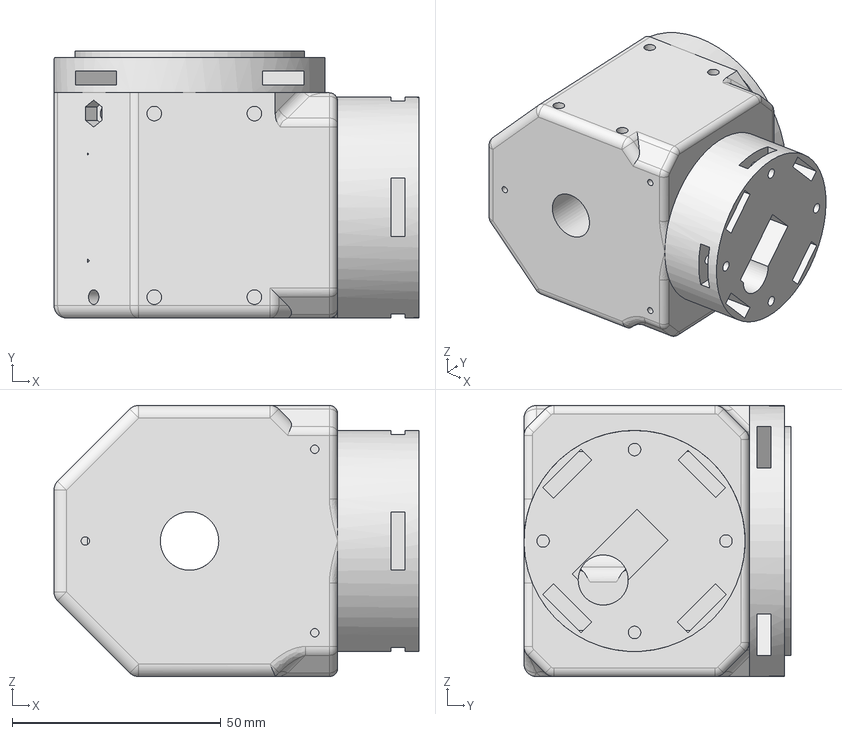
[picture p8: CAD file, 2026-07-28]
Hardware/Models/Reference/onshape-v1/parts-step/KP0013-01_MainPivotV2.step
87.5 x 64.0 x 65.0 mm

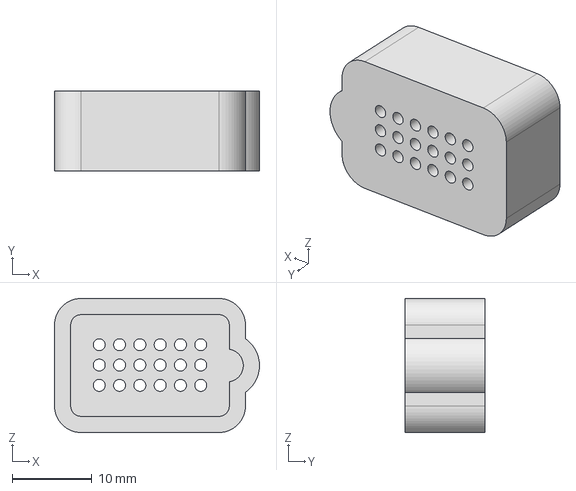
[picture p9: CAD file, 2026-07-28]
Hardware/Models/Reference/onshape-v1/parts-step/KP0045-01_MainESocketMaSM.step
25.7 x 10.0 x 16.8 mm

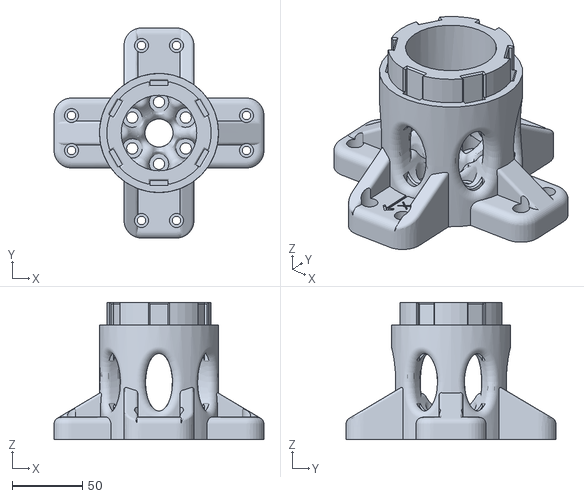
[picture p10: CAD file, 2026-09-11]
Hardware/Models/100-Base/110-001_BaseMountBottom.stl
150.0 x 150.0 x 98.0

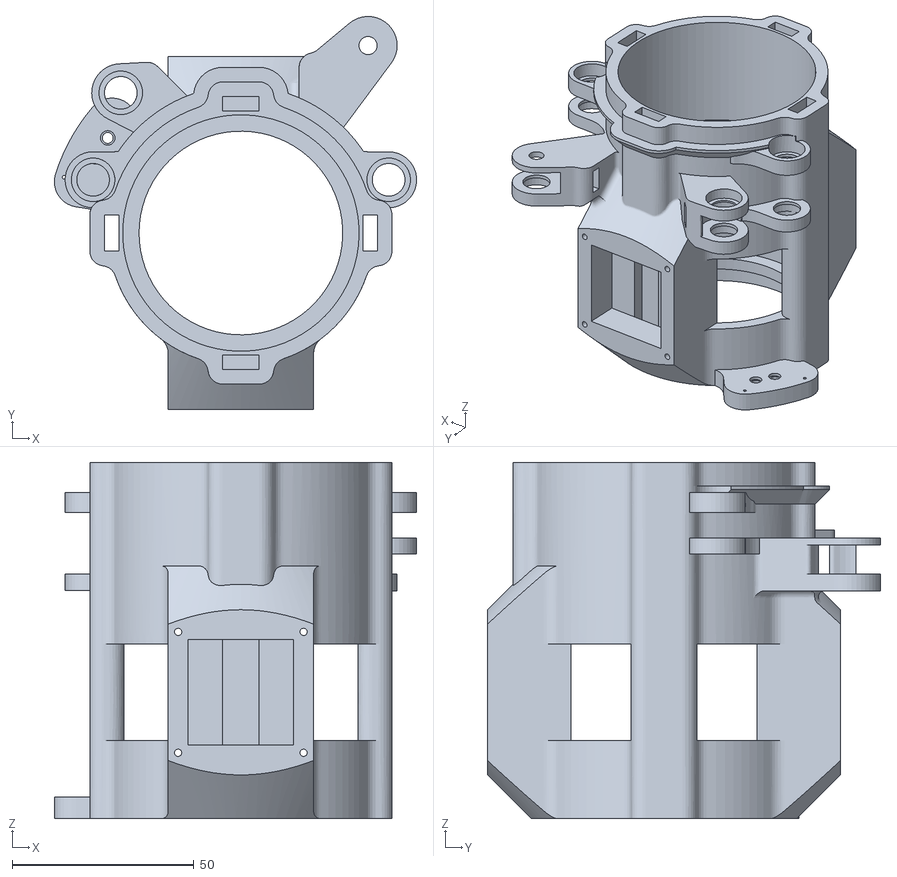
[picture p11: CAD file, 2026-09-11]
Hardware/Models/200-ArmBody/200-001_ArmBody.stl
99.6 x 108.1 x 98.0

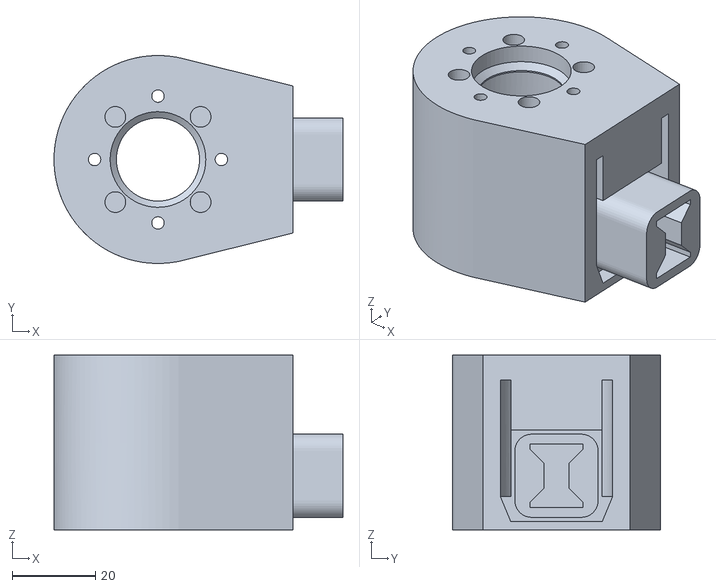
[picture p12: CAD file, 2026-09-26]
Hardware/Models/400-EndArm/420-001_EndArmHub.stl
69.5 x 50.0 x 42.0

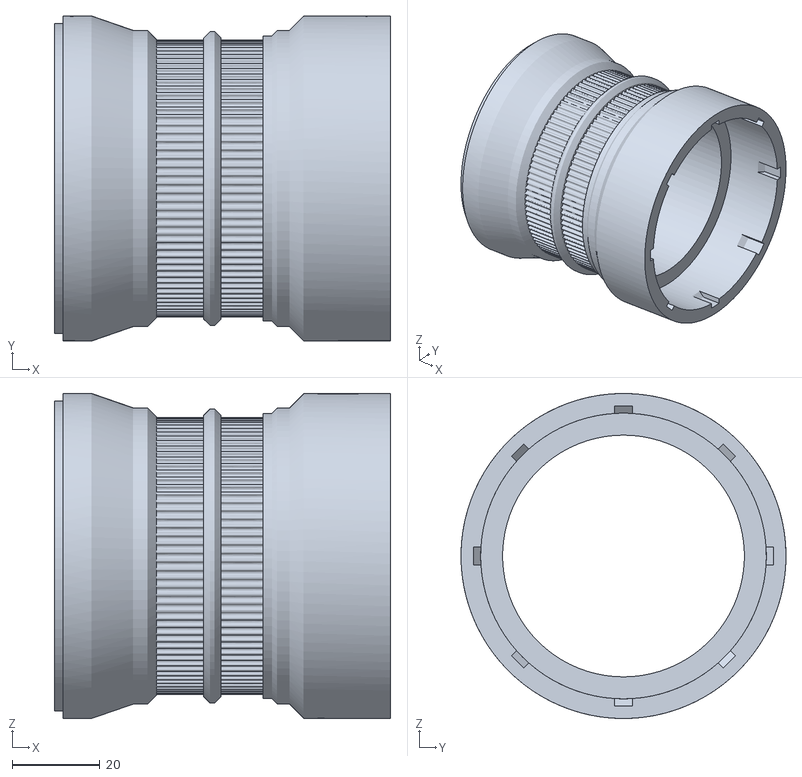
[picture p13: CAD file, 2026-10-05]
Hardware/Models/500-ExternalGear/510-001_ExternalGear.stl
76.5 x 73.9 x 74.0

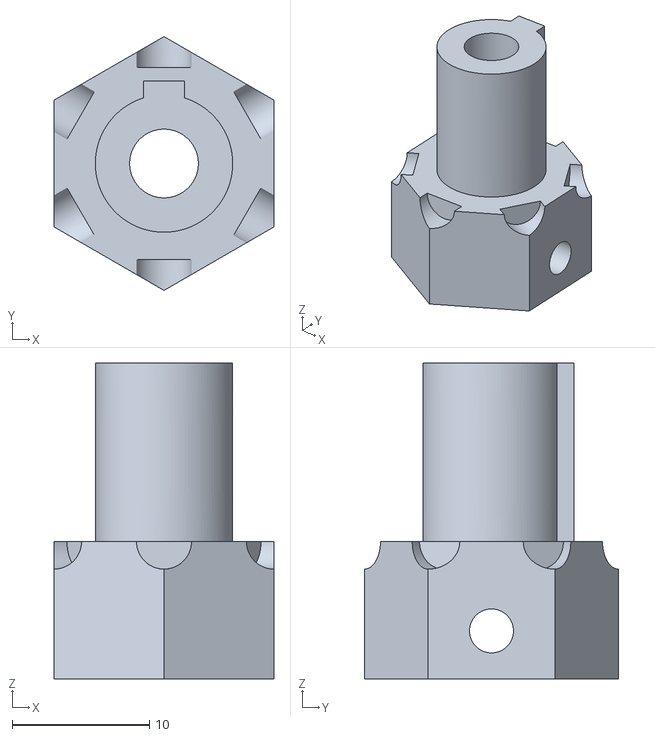
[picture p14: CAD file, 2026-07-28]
Hardware/Models/600-StrainWave/630-004_WaveGenCoupler.stl
16.0 x 18.5 x 23.0

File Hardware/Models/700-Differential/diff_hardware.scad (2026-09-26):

// 700-Differential bought-part stand-ins — the bearings and the rod, drawn
// only so the assembly reads as a machine (DC-2).
//
// NOTHING HERE IS A PART MODEL. None of it is printed, none of it is gated
// against a reference, and no dimension below is a measurement. Each module
// draws the ENVELOPE a catalogue part occupies, with just enough shape to be
// recognisable in a render: a bearing shows two races and a sunk shield, the
// rod shows its bore. What they are for is negative space. The seven printed
// parts are dimensioned around these, so a seat that reads as an empty gap in
// the assembly is a placement mistake, and a seat that reads as full is one
// that was checked. Drawing them is the only way to tell those two apart by
// looking.
//
// NO SIZE IS TYPED HERE. Every module takes one of diff_params.scad's
// catalogue triples, [ID, OD, width], so re-specifying a bearing there moves
// both the seat that holds it and the stand-in that fills it. The one number
// this file does choose is how coarsely to draw them: these are illustrations,
// so they are drawn at HW_FN rather than at the $fn the measured parts need.

include <diff_params.scad>

/* [Hidden] */
HW_FN     = 48;     // stand-ins are drawn, not measured
HW_SHIELD = 0.35;   // how deep a shield sits below the race faces

// One ring of a stand-in, between a surface a part bores and a surface a part
// turns. A seat is bored to the catalogue diameter the stand-in is drawn at, so
// without something between them the two surfaces coincide exactly. Each ring
// is drawn DRAW_JOINT off both catalogue diameters, which is enough that no
// surface here coincides with a surface of a part — the allowance
// diff_params.scad defines, and the reason for it. The stand-in is what moves:
// it is an illustration, and the seat is the part.
module hw_ring(id, od, h) {
    tube(id = id + 2 * DRAW_JOINT, od = od - 2 * DRAW_JOINT, h = h,
         anchor = BOTTOM, $fn = HW_FN);
}

// A deep-groove ball bearing: an outer race, an inner race, and a shield sunk
// between them on both faces. Anchored on its own bottom face, so that placing
// one is a single z — the seat's own floor — and never an arithmetic.
module bearing(spec) {
    id = spec[0];  od = spec[1];  w = spec[2];
    race   = max(0.6, (od - id) / 5);
    shield = min(HW_SHIELD, w / 6);
    difference() {
        hw_ring(id, od, w);
        down(epsilon)
            tube(id = id + race, od = od - race, h = shield + epsilon,
                 anchor = BOTTOM, $fn = HW_FN);
        up(w - shield)
            tube(id = id + race, od = od - race, h = shield + epsilon,
                 anchor = BOTTOM, $fn = HW_FN);
    }
}

// A needle roller thrust bearing between its two washer races (#710-006 is the
// AXK cage; the two AS races are listed with it). Drawn as three stacked rings
// because the stack's height is what the seat has to clear, and that is the
// sum of all three rather than the cage alone.
module thrust_stack(spec = THRUST_AXK0819, race_w = 1.0) {
    id = spec[0];  od = spec[1];  w = spec[2];
    hw_ring(id, od, race_w);
    up(race_w)
        tube(id = id + 0.5, od = od - 0.5, h = w, anchor = BOTTOM, $fn = HW_FN);
    up(race_w + w)
        hw_ring(id, od, race_w);
}

function thrust_stack_h(spec = THRUST_AXK0819, race_w = 1.0) =
    spec[2] + 2 * race_w;

// The #720-006 carbon fibre rod, drawn as the tube it is: its bore is the tool
// conductors' path, so a solid cylinder would misrepresent what the assembly
// has room for. Anchored on its own bottom face, like the bearings.
module cf_rod(len = CF_ROD_LEN) {
    hw_ring(CF_ROD_ID, CF_ROD_D, len);
}

// A #680-001 wire brad: the pin that locks the Split Gear's two halves to each
// other (008.6 steps 7-9), driven radially and trimmed flush. Drawn lying on
// +X from the origin, like the bearings are drawn from their bottom face, so
// placing one is a rotation and a radius and never an arithmetic.
//
// It is drawn at BRAD_D, which is LARGER than the Ø1.5 holes it sits in, and
// that overlap is the point: the fit is an interference, the brad cutting its
// own seat as it goes. Drawing it at the hole's diameter would show a clearance
// the part does not have.
module brad(len) {
    yrot(90) cyl(d = BRAD_D, h = len, anchor = BOTTOM, $fn = HW_FN);
}

// A GT2 belt run between two pulleys is not modelled: the belts leave the
// differential through Diff Body A's arm slot and their path is set by the
// upper arm, which is outside this model set. The slot itself is geometry and
// is in 730-001.

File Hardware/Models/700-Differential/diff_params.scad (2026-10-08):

// 700-Differential shared parameters — the single source of truth for the
// parametric differential model set (DC-2, specs/009-Design-Completion.md).
//
// Every part file includes this file. Two parameter sets are selectable:
//   config = "revised"  — the DC-2 authored configuration meeting the
//                         interface in specs/004 § Differential interface: it
//                         fits the HDI-940 cover envelope and drills the Split
//                         Gear's brad holes on one axis.
//   config = "previous" — faithful recreation of the previous version's
//                         differential; renders match the reference STLs.
// No configuration here reaches the firmware file's L4 = 59.50 mm, and none is
// meant to: L4 is specified at 39.50 mm in specs/003 § Link lengths, and no
// part here is driven to either figure.
//
// "revised" is the default, and is the setting to keep: it is the model set
// that is worked on and printed (specs/004 § Wrist and differential), so a
// file opened or rendered without a -D sees the new models. "previous" is
// selected with -D config="previous" when the reference meshes are wanted;
// render.rs --verify names the configuration on every render, so its gates do not
// depend on this default.
//
// Dimensions are stated once here; part files and specs reference them.

include <BOSL2/std.scad>
include <../gt2_pulley.scad>
include <../print_fit.scad>

/* [Configuration] */
// Parameter set: revised (004 interface, the default) or previous (matches reference STLs)
config = "revised"; // [revised, previous]

/* [Hidden] */
$fn = 128;
epsilon = 0.01;

// The gap drawn between two surfaces that are designed to meet exactly, in mm.
//
// Where a part touches another over a whole surface — a bearing in a seat bored
// to its own diameter, two halves bolted face to face — drawing both at nominal
// makes those surfaces coincident: the solids touch everywhere and
// interpenetrate nowhere. CGAL cannot union a tangency. What it returns is a
// solid that is not a 2-manifold, and such a solid still exports, so the
// failure need not be immediate or loud: a composition holding one either warns
// that the object may not be a valid 2-manifold, or stops outright at "CGAL
// ERROR: assertion violation!" in applyUnion3D, which names no file. Drawing
// one of the two surfaces this far clear of the other leaves the solids
// separate and the union simple.
//
// This is a drawing allowance, not a design clearance. It says nothing about
// how the parts fit, and no seat, bore or part dimension derives from it. The
// size is chosen from both ends: it is a thousand times OpenSCAD's own 1e-6 mm
// vertex grid, so an importer cannot merge the two surfaces back together, and
// it is two orders below the 0.15 mm the parts are measured to, so nothing the
// harness gates on can see it.
DRAW_JOINT = 0.001;

// The print-fit clearances every part draws, per side (../print_fit.scad):
// zero in "previous", which is the reference meshes, and the classes'
// values in "revised". PRESS is for a bought mate (bearings, the CF rod,
// tube and strakes), SLIP for a printed mate and fastener clearances, and
// RUN for a gap between parts that turn past each other without touching.
// Each part's header says which of its features take which.
SLIP  = fit_clearances(config)[0];
PRESS = fit_clearances(config)[1];
RUN   = fit_clearances(config)[2];

// ---------------------------------------------------------------------------
// Off-the-shelf interfaces (007.1 parts catalog: [ID, OD, width] in mm).
// Parts reference these rather than restating a diameter, so re-specifying a
// bearing propagates to every seat that takes it. A few entries are recorded
// for reference and consumed by no geometry; each says so.
// ---------------------------------------------------------------------------
BRG_6705  = [25, 32, 4];    // #620-004, Diff Body A
BRG_6703  = [17, 23, 4];    // #620-003, 5 seats in the differential's own parts
                            //   and a 6th that 008.6 step 2 puts in #420-001
BRG_MR128 = [8, 12, 3.5];   // #620-002, 4 seats: shaft ends, and one per Split
                            //   Gear half. Both counts corrected under DC-11(e)
BRG_MR85  = [5, 8, 2.5];    // #620-001, into the Diff Gear Axle's back bore
THRUST_AXK0819 = [8, 19, 2];   // #710-006 needle thrust; 2x AS0819 races 8x19x1

// The bore of a shoulder that bears on a bearing's OUTER race: halfway across
// the bearing's section. A shoulder bored any smaller also bears on the inner
// race and brakes the bearing it locates. In "revised" every such shoulder is
// bored to this; "previous" keeps the reference's own bores. Body A's Ø20
// waist under its 6703 was already bored to it.
function shoulder_bore(spec) = (spec[0] + spec[1]) / 2;

L3_TUBE_ID  = 20.07;        // C-505 L3 tube's inside dimension, over Body A's
                            //   20 x 20 arm spigot
CF_ROD_D    = 8;            // #720-006 CF rod OD
CF_ROD_ID   = 6;            // #720-006 CF rod bore; the tool conductors' path
CF_ROD_LEN  = 96;           // reference: cut length, set by 008.6 not by geometry
STRAKE_25   = [25, 5.6, 2.5];   // #710-005, 3x. The slots are in the Split
                                //   Gear TOP, and are drawn 5.600 x 2.500 for
                                //   a 5.588 x 2.337 strip -- 0.012 mm across
                                //   the width, the robot's tightest bond fit
                                //   (007.1 C-502). 008.6 step 11 named the
                                //   Bottom, which carries no slot - DC-11(e)
// #720-005 (5x 60 x 4.4 x 1.5) was listed in 007.6. No assembly step places
// it, no part here carries a slot that would take it, and the build record
// does not call for it, so the row is withdrawn - DC-11(e). The constant is
// gone with it; nothing in this model set referred to it.
BRAD_D      = 1.8;          // #680-001 1" #19 finishing nail (locking dowel)

// Where the Split Gear's brad holes are drilled, on the halves' shared z. The
// two halves are locked to each other by driving brads through four radial
// holes (008.6 steps 7-9), which only works if both are drilled on ONE line —
// so the axis belongs to neither part and is stated here.
//
// The references disagree about that line by 0.500 mm, on a Ø1.5 hole. On
// 710-002 a meridional section cuts the hole at 0 degrees and reads a notch
// spanning z 12.002..13.498, an axis at 12.750; on 710-001 the chords through
// the cage band fit a Ø1.497 hole on an axis at 12.250. Nothing in the
// assembly can absorb it: the halves meet face to face on 710-001's Ø23 seat
// floor and again on the gear's parting cone, so their relative position is
// fixed twice over. As referenced there is no straight line through both.
//
// "revised" drills both at 12.750. "previous" keeps each part's own reference
// value, because the DC-2 comparison measures the reference and would report a
// deliberate move as a miss. 12.750 is the height kept because it is the one
// both parts have material for: it leaves a full millimetre of 710-002's Ø27
// wall below the hole (that wall starts at z 11.000, so 12.250 would leave
// 0.500 mm), while 710-001's cage tube spans z 9.990..16.010 and takes either.
// It is also the blind, glued half — the half whose hole actually holds the
// brad — so it is the half whose position should not be the one that moves.
BRAD_Z      = 12.750;
BRAD_Z_TOP  = config == "previous" ? 12.250 : BRAD_Z;
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

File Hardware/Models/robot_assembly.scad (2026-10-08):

// robot_assembly.scad — whole-robot composition.
//
// Places the printed parts, the structural stock and the cover envelopes in
// their assembled positions, so the build can be reviewed by looking at it and
// so a part that is missing shows up as a hole rather than as an absence
// nobody notices. It is the counterpart of 700-Differential/diff_assembly.scad
// one level up: that file composes one subassembly, this one composes the arm.
//
// FRAME. The CAD model frame: +y runs along the arm from the base mount, +z
// across the arm, +x out to the tool. This is the frame specs/003 § Link
// lengths states the joint stations in and the frame specs/004 § Differential
// interface measures Diff Body A in, so it is the frame the spec set already
// speaks. It is not specs/003 § Coordinate frame's operator frame, which is
// Z-up; relating the two is a question about the pose this model is drawn in,
// and nothing here depends on the answer.
//
// J2 and J3 run along z. J1 runs along y. J5 runs along x, out through the
// tool. J4 runs along z, which the wrist section below reads off two mating
// features rather than assuming.
//
// WHAT PLACES WHAT. Every placement below is solved from a feature the part
// itself carries, matched against the CAD assembly in dde/HDIMeterModel.gltf —
// the same file specs/003 and specs/004 read the joint stations from. The
// derivation is written at each call site and names the feature, because a
// placement that cannot be traced to a feature is a guess that renders.
//
// Two rules keep that honest:
//
//   1. A mating feature outranks a bounding box. Where a printed part and its
//      CAD body disagree in size — and two of them do — the part is placed by
//      the face that locates it in the build, and the disagreement is recorded
//      at the call site rather than split between the two ends.
//
//   2. A part whose placement is not determined by anything in the model set
//      is NOT drawn at a plausible position. It goes in UNPLACED below. The
//      value of this file is that the holes in it are real.
//
// THE WRIST LANDING, AND THE TWO FEATURES THAT FIX IT. The differential
// arrives on one transform. Both halves of it are read off a mating feature,
// and neither is chosen:
//
//   Along the arm. Diff Body A's -x end is a 20 x 20 R4 spigot, 386.245 mm2 in
//   section over a 12.700 x 15.304 bore of 131.7156 mm2, and the End Arm Hub's
//   L3 plug is the same spigot -- 386.068 mm2 over the same bore, 131.7158 mm2,
//   the two bores agreeing to two parts in a million. They are the two ends of
//   the one C-505 tube, so Body A's spigot points back down the forearm and the
//   differential frame's -x runs onto this frame's -y.
//
//   Across the arm. The Diff End Pulley hangs off the CF rod below the
//   differential centre, at that assembly's own z -18.838..-8.588, and the belt
//   that drives it comes from the elbow, whose four pulleys stand at
//   z 78.500..96.500 here. The pulley faces the side they are on, so the
//   differential frame's -z runs onto this frame's +z and the J4 axis onto -z.
//
// Those two fix the third: the remaining row is their cross product, which is
// what makes WRIST_BASIS below a proper rotation and the whole of the
// transform. Both features also put the J4 and J5 axes through one point, as a
// bevel differential requires and as 700-Differential/diff_assembly.scad
// asserts of its own frame, so the assembly is placed by its diff_centre() --
// which lands on the J4 axis, at the J4 station. The wrist frame below states
// what fixes it there and what putting it anywhere else costs.
//
// WHAT THE LANDING THEN MEASURES, none of it fitted. Body A's spigot axis lands
// on (x = 0, z = 35.5335) along y, against the C-505 tube's own
// (x = 0, z = 36.000): coaxial to 0.4665 mm, which is the size of the residuals
// these measured parts already carry. Its 6 x 6 belt slot runs down the spigot
// on x +/-3, z 32.5335..38.5335 -- inside the tube's 20.07 mm bore -- and opens
// at the tip, facing the elbow the belts come from. The spigot is 21.000 mm
// long, against the 16.0 mm of it C-505 laps at the hub.
//
// FOUR READINGS ARE WITHDRAWN, and all four were one mistake. This file drew
// the differential four ways, on the grounds that specs/003 § DH model reads
// the J4 axis parallel to J3 while specs/004 § Differential interface fits Body
// A to the gripper covers by a radius bounding two perpendicular directions at
// once. All four sent the differential frame's -x onto this frame's +x, on the
// reading that Body A's arm is the tool mount. It is not: it is the L3 spigot,
// and the section above is what says so. 003's reading survives -- J4 does run
// along z -- but neither record addressed the quarter turn about that axis, and
// that turn is what the spigot settles. 004's argument is withdrawn with the
// readings it produced: ENV_GRIPPER's +/-30.250 in x and z about z = -2.000 is
// the gripper cover's own section about the tool axis, which begins at the J5
// station and runs out to the tool, and it bounds no plate of Body A's.
//
// WHERE THAT LEAVES THE COVERS. Body A lands inside ENV_L3_SKIN, the forearm
// skin, and inside none of the three wrist boxes, every one of which ends at or
// below z = 18.000 while this axis runs at z = 36.000. The skin begins on that
// same z = 18.000 plane and runs to 65.001, so over the wrist the skin and
// ENV_DIFF_COVER read as the two halves of one shell split there, and the
// differential sits in the upper half. What the wrist boxes measure on their
// own is then either a revision the printed differential does not match -- as
// the Main Pivot's and the Arm Body's already are -- or a cover the measured
// set is missing, and the echoes report it rather than absorbing it.
//
// THE L3 JOINT, WHICH THE LANDING CLOSES. The forearm's far end was read as
// open. The End Arm Hub's tube spigot and the 243 mm C-505 tube put the tube's
// far face 36.000 mm short of the J4 station, and specs/009 DC-11(h) was opened
// on the part that closes that span. There is no such part, and no longer cut
// either: Body A's spigot tip stands 51.000 mm back from the J4 axis, so the
// spigot crosses the whole 36.000 mm and reaches 15.000 mm inside the tube. Of
// its 21.000 mm, 15.000 are lapped and 6.000 stand proud of the tube's end.
// Both ends of C-505 are therefore female over the same 20 x 20 R4 male plug,
// 16.0 mm of lap at the hub and 15.000 mm here, and nothing is drawn for the
// span because nothing is missing from it.
//
// RENDERING IT. A preview needs nothing but this file. A full render asks CGAL
// for a closed solid of everything drawn, the nine meshes 700-Differential/
// imports included, so it needs the cache that render.rs --meshes
// builds, which makes each mesh renderable as it goes: the render program's header
// says why a mesh that previews correctly can still stop a render, and running
// it is the one step this file cannot take for itself. Expect minutes rather
// than seconds either way, since a render converts every imported mesh.

include <BOSL2/std.scad>

// The differential subassembly, for place_differential(). `use` imports its
// modules and diff_centre() without firing its own top-level call, echoes or
// asserts, and leaves its mesh paths resolving against its own directory.
use <700-Differential/diff_assembly.scad>
// The External pulleys are sources, not meshes: their tooth count follows the
// same `-D config=` switch as the differential (DC-12).
use <400-EndArm/430-001_ExternalOuterPulley.scad>
use <400-EndArm/430-002_ExternalInnerPulley.scad>

/* [View] */
// The differential subassembly, on the landing WRIST_BASIS states.
show_differential = true;
// Printed parts, from the group directories.
show_parts = true;
// Carbon fibre tube stock, drawn from its catalogued section and cut length.
show_stock = true;
// Joint stations and axes.
show_frame = true;
// Cover envelopes, as boxes from the CAD bodies' measured extents.
show_envelopes = true;

/* [Hidden] */
$fn = 64;
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

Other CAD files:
Hardware/Models/800-Harness/800-004_MainPivotPlugB.stl
Hardware/Models/700-Differential/DiffA2CodeDiskEndStop.dwg
Hardware/Models/800-Harness/800-007_PCBSpacer.stl
Hardware/Models/900-ToolInterface/912-002_SpanDriver.step
Hardware/Models/200-ArmBody/200-002_PivotStatorHolder.scad
Hardware/Models/100-Base/100-001_BaseClamp.stl
Hardware/Models/100-Base/100-002_BaseCodeDisc.stl
Hardware/Models/100-Base/100-003_PivotSkirt.stl
Hardware/Models/100-Base/110-002_BaseStatorHolder.scad
Hardware/Models/100-Base/110-004_BaseMountingPlate.scad
Hardware/Models/100-Base/120-001_BaseLong.stl
Hardware/Models/200-ArmBody/200-003_StatorBalancer.stl
Hardware/Models/200-ArmBody/200-006_CalibrationArrows.stl
Hardware/Models/200-ArmBody/210-001_IdlerPlug.stl
Hardware/Models/200-ArmBody/210-002_BeltDirectorPulley.stl
Hardware/Models/200-ArmBody/210-004_SmallBeltDirector.stl
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

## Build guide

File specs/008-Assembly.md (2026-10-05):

# 008 — Assembly

This document is the procedure that builds the parts in [007-Bill-of-Materials.md](007-Bill-of-Materials.md)
into the robot specified in [004-Mechanical-Architecture.md](004-Mechanical-Architecture.md). It is a
**derived artifact** — regenerate it when the mechanical design changes. Its step text descends from the
upstream [HD Build Notes](https://github.com/HaddingtonDynamics/Dexter/wiki/HD-Build-Notes), corrected
against the model set wherever the two disagree; that page also lists the parts each subassembly consumes,
which is a second witness to [007](007-Bill-of-Materials.md)'s quantities. Steps for subassemblies with an
open item (the bolted base, the differential, the revised link lengths) are the current procedure of
record; confirm the corresponding [009-Design-Completion.md](009-Design-Completion.md) item before
committing irreversible work (cutting CF, pressing strain-wave splines). A from-scratch build ends
with the firmware/calibration bring-up in [008.12](#00812-firmware-configuration-and-calibration).

## Assembly order

```mermaid
flowchart TD
    A[008.1 Glue Rig] --> B[008.2 Base]
    A --> C[008.3 Harmonic Drive Motors]
    B --> D[008.4 Main Pivot]
    C --> D
    D --> E[008.5 Arm Body]
    E --> F[008.6 Differential]
    F --> G[008.7 End Arm Hub]
    A --> G
    C --> H[008.8 External Gear]
    G --> I[008.9 Belts]
    H --> I
    E --> J[008.10 Wire Harness]
    I --> J
    J --> K[008.11 Tool Interface]
    K --> L[008.12 Firmware & Calibration]
```

## General tools and consumables
- Two-part epoxy; cyanoacrylate ("super") glue; hot glue gun; threadlocker (e.g. Loctite 243)
- Rubber mallet; a short aluminum strake as a bearing drift; bearing/arbor press (for strain-wave flex-spline
  pressing)
- Wave-generator depth-setting tool (a shop-made depth gauge; confirm form during 008.3)
- Cordless drill with small chuck (reaming; improvised reamer from cut pin stock)
- Soldering iron, solder, heat-shrink, wire strippers
- Phillips and small flathead screwdrivers (the flathead spins M2 nuts too small for a wrench)
- **Grounded anti-static wrist strap** whenever handling the FPGA board (present from 008.10 onward)
- WinSCP and PuTTY (or equivalent) for 008.12

**Conventions.** The bonding, tightening, and torque conventions in
[004 § Materials and construction methods](004-Mechanical-Architecture.md#materials-and-construction-methods)
apply to every step below and are not repeated per step.

---

## 008.1 Glue Rig Assembly
Parts: [007.1](007-Bill-of-Materials.md#0071-glue-rig-assembly). Prints the epoxy jigs (tooling, not robot
parts) that hold each bonded span at its finished spacing while adhesive cures. The jigs and the span each
one holds are listed in [007.2 § Tooling](007.2-Printed-Parts.md#tooling--glue-rigs).

1. Lap each rig's `_A` and `_B` halves into one jig. Glue up one span at a time.
2. Clear all mating surfaces of first-layer print residue before gluing.
3. Dry-fit every part on the rig before applying epoxy.
4. Use a CF strake to lock the Axis Intersection so it cannot shift while curing.
5. Apply epoxy to both mating surfaces of each joint; do not over-apply — wipe excess before cure.
6. Confirm parts sit flush and level; weight them if needed.
7. Cure per the epoxy manufacturer's time before removing.

## 008.2 Base
Parts: [007.2](007-Bill-of-Materials.md#0072-base).
1. Open the eight bolt holes in the Base Mount Bottom flange to **Ø6.6 mm through with a Ø11.0 mm
   counterbore** on the flange's upper face. As printed they are Ø6.000 with a Ø10.000 counterbore, which
   is under size for M6 on both diameters.
2. Bolt the Base Mounting Plate to the Base Mount Bottom with the 8 × M6 × 18 mm screws, driven **from
   inside the base** — the heads seat in the flange counterbores, so the plate goes on before anything
   closes the base over them. Pattern and hole sizes:
   [004 § Base mounting plate](004-Mechanical-Architecture.md#base-mounting-plate).
3. Epoxy the 133 mm CF strakes into the Base Mount Bottom and Base Long, filling every other slot — the two
   parts slide together and lock.
4. When epoxying the Base Long, leave the strakes protruding ~6 mm (1/4") so the Base Code Disk has a surface
   to rest against.
5. Bolt the plate to the work surface through its 4 × Ø6.6 mm corner holes with M6 bolt, washers, and nut,
   or clamp the same four corners to a T-slot table. The plate must be fixed down, not left resting —
   [004 § Base mounting plate](004-Mechanical-Architecture.md#base-mounting-plate).
6. Assemble the Base Clamp: place an M3 nut in the hex pocket on one ear and thread in an M3 × 20 mm bolt
   from the counterbored ear. The clamp is installed later, in [008.4](#0084-main-pivot) step 17.

## 008.3 Harmonic Drive Motors
Parts: [007.3](007-Bill-of-Materials.md#0073-harmonic-drive-motors). Builds the base (J1) and pivot (J2)
motor assemblies (repeat for the J3 external-gear motor in [008.8](#0088-external-gear)). Before printing J3's
Flex Spline Attach, measure its motor's body length, set it as `MOTOR_LEN` in
[`exgear_assembly.scad`](../Hardware/Models/500-ExternalGear/exgear_assembly.scad), and print the Attach with the
`hub_drop` that file echoes as `j3_hub_drop` ([007.2](007.2-Printed-Parts.md#printed-parts)).

1. Assemble one drive at a time.
2. Keep each strain-wave drive's top and bottom halves paired — they are matched at manufacture and are not
   interchangeable between drives.
3. Remove first-layer print residue from the Flex Spline Attach.
4. Lubricate, then press the flex spline's hub onto the Flex Spline Attach with a press: its Ø11 bore over
   the spigot and its six holes over the nubs.
5. Separate them and inspect for print residue pushed into the attachment nubs during pressing; remove any.
6. Clamp the hub, before the Attach goes on the motor, because the screw heads sit in its underside:
   a. Refit the hub over the spigot and nubs.
   b. Press an M2 nut into each of the Flex Spline Cap's six traps. Set the Cap inside the cup, its land
      down on the hub and its holes over the nubs.
   c. Drive 6× M2 × 12 mm screws up through the Attach's head pockets, the nubs and the hub into the nuts,
      cross-pattern, until snug.
7. Secure the Flex Spline Attach to the motor with 4× M3 × 10 mm bolts (confirm size/qty against the build).
8. Press M3 nuts into the Wave Gen Coupler, insert M3 × 8 mm hex bolts to retain them, then epoxy over the
   nut heads to lock them; cure.
9. Ream the Wave Gen Coupler and lubricate before sliding it onto the motor shaft.
10. Use the wave-generator depth-setting tool to set the coupler depth on the shaft. The depth puts the wave
    generator where the drive's drawing puts it against the flex spline: its hub's outer face the overall
    axial length [C-201](007.1-Parts-Catalog.md#c-201--521-strain-wave-component-set) gives beyond the
    flex spline's mounting face. J3's Attach carries that face lower on its motor by its `hub_drop`, so a
    tool that gauges from the motor face is reset for J3.
11. Tighten the M3 × 8 mm hex bolts evenly (alternate a few turns each) until snug — do not over-tighten the
    printed mount.
12. Mount the drive's top half, its circular spline, in the joint's Stator Holder (`#110-002`, `#200-002` or
    `#511-002`, printed `config="revised"`):
    a. Press an M3 nut into each of the six hex pockets in the holder's back face and push it to the
       pocket's end.
    b. Seat the circular spline in the recess, stamped "52" outward, with its Ø38 step in the pilot bore
       and its six holes over the pockets.
    c. Drive 6× M3 × 12 mm socket-head screws through the spline into the nuts, cross-pattern, until snug.
       In the Base and Pivot holders the tips stand 1 mm proud of the back face, inside the drive's
       Ø50 circle.

## 008.4 Main Pivot
Parts: [007.4](007-Bill-of-Materials.md#0074-main-pivot). Consumes 2× motor assemblies from
[008.3](#0083-harmonic-drive-motors) and the Base from [008.2](#0082-base).

1. Epoxy the 126 mm CF strakes to the Main Pivot's short end and the 146 mm strakes to the long end; epoxy
   both the body holes and strake ends.
2. Epoxy both ends at once — internal weep holes connect them and epoxy mixes inside; wipe weeped excess.
3. Confirm both strake sets protrude by about the same distance once seated.
4. Press the two Motor End Caps — Base `#311-001` and Pivot `#312-001` — onto two 6810 bearings.
5. Slide the two-sided Pivot Code Disk onto the Main Pivot, flat side facing away from the body.
6. Epoxy the Pivot Motor End Caps to the Main Pivot; orient the long-end cap's notch toward the motor-wire
   hole in the long end (short-end cap orientation is free — its wire hole is centered).
7. Feed the two motor assemblies' wires through the side holes and pull them through.
8. Epoxy the motor bottoms, End Cap faces, and the strake-to-motor contact areas.
9. Mount the Main Pivot onto the Base:
   a. From the Base Long's lower end, press a 6810 bearing into the lower bore until it stops on the bore's
      shoulder, 35.5 mm (about 1½″) in (mallet + aluminum drift if it resists).
   b. Align the Base Code Disk with the 3 strakes and press to snap in.
   c. Push the Base Long, lower end up (wires up), onto the Main Pivot until the Base Motor End Cap's bearing
      bottoms in the Base Long's upper bore, flush with its top face.
   d. Remove the Flex Spline Attach socket-head screws one at a time, adding a #6 washer under each; the
      washers retain the lower bearing's inner race, which runs free on the Attach's land, and lock the motor
      while adhesive cures.
10. Mount the strain-wave top in the Base Stator Holder ([008.3](#0083-harmonic-drive-motors) step 12).
11. Slide the Base Stator Holder onto the Base Long strakes, pressing down while occasionally rotating the
    motor shaft.
12. Prepare 3× M3 × 105 mm all-thread: apply threadlocker, thread an M3 nut flush at one end.
13. Slide the Base Stator Holder fully onto the strakes.
14. Slide the 3 all-thread rods into every other hole of the Base Stator Holder.
15. Set the Base Long onto the Base Mount and rotate until the Main Pivot notch lines up with the rods.
16. Add a #6 washer and M3 nut onto each rod and tighten (all 3), keeping the notch aligned.
17. Install the Base Clamp (from [008.2](#0082-base) step 6): remove the Base Long, slide the clamp onto the
    Base Mount until it seats on the shoulder, reinstall the Base Long fully down on the Base Mount's top
    face, and tighten the clamp — see
    [004 § Base mounting plate](004-Mechanical-Architecture.md#base-mounting-plate). Measure the
    mounting-face-to-J2 height per
    [009.1 § 3.1](009.1-Performance-Characterization-Protocol.md#test-31-mounting-face-to-j2-axis).

## 008.5 Arm Body
Parts: [007.5](007-Bill-of-Materials.md#0075-arm-body).

1. Press a 6810 bearing ~38 mm into the Arm Body.
2. Slide the Arm Body over the Pivot Motor and snap in.
3. Remove the M3 × 12 mm socket-head screws one at a time, adding a #6 washer under each, and retighten; the
   washers retain the bearing's inner race on the Flex Spline Attach's land.
4. Mount the strain-wave top in the Pivot Stator Holder ([008.3](#0083-harmonic-drive-motors) step 12).
5. Slide the Pivot Stator Holder onto the Arm Body, pressing while rotating the motor shaft.
6. Tap the 4 Stator Balancers into place with light mallet taps (they are fragile).
7. Assemble the Belt Directors:
   a. Press the 6 MR128 bearings **onto** the belt director shanks, two per body — the shank is the bearing
      bore, not a housing ([007.2](007.2-Printed-Parts.md#arm-body-and-belt-directors--0075)).
   b. Apply a drop of super glue **inside** each Belt Director (not on the cap — cap glue can seep into and
      lock the bearing).
   c. Push the Large and Small Belt Directors through front to back, then press the Caps in from the back.
8. Idler: fit the MR85 bearing onto the Idler Plug shaft, then screw in the M2 × 20 mm bolt back to front.
9. Hold the Belt Director Pulley between the two halves, push the Idler Plug through back to front, and press
    together.
10. Place the M3 washer, then M2 washer, then M2 nut, and tighten.

## 008.6 Differential
Parts: [007.6](007-Bill-of-Materials.md#0076-differential). Parametric source in
[`Hardware/Models/700-Differential/`](../Hardware/Models/700-Differential/).

**Before printing:** print `config="revised"`. It carries the 80T inputs and fits the `HDI-940` covers
([004 § Differential interface](004-Mechanical-Architecture.md#differential-interface)), and is unproven on
a physical build until the DC-9 checklist passes. `config="previous"` nets the previous version's 5.625:1
wrist, which does not match `AxisCal` ([DC-12](009-Design-Completion.md#wrist-pulley-rework)). The former `710-002` scale defect is resolved
([DC-11(f)](009-Design-Completion.md#procurement-data)).

1. Insert one 6705 and one 6703 bearing into Diff Body A; press to seat.
2. Insert one 6703 into the End Arm Hub; press to seat.
3. Insert 2× 6703 into Diff Body B (one each side); press to seat.
4. Insert 2× MR128 into the Diff Gear Shaft (one each end); press to seat.
5. Insert one 6703 and one MR128 into the Split Gear Top (fitted locations); press. The 6703 goes in the
   Ø23 pocket z 4.000–8.750 and is what the Split Gear Bottom's Ø17 stub then enters, so it must be in
   before step 8 — step 8 turns one half against the other on it.
6. Insert one 6703 and one MR128 into opposite sides of the Split Gear Bottom; press.
7. Ream the 4 side holes of the Split Gear Top ~6 mm deep.
8. Press the Split Gear Top into the Split Gear Bottom; rotate until the 4 holes show through the 4 windows.
9. Through each window, insert a 1" #19 wire brad with super glue ~6 mm deep; trim flush once set.
10. Push a zip-tie flat end into each window as far as it goes, hot-glue, and trim flush.
11. Epoxy the 3 25 mm CF strakes into the Split Gear **Top** slots; cure. The three slots are cut from
    that part's base at 90°, 210° and 330° and run up to z 8.000. The Split Gear Bottom carries no slot
    ([DC-11(e)](009-Design-Completion.md#procurement-data)).
12. Press the Diff Gear Shaft into Diff Body B.
13. Coat the bore of the Diff Shaft Pulley (`#720-004`) with epoxy, and set it in Diff Body A's pulley
    chamber through the +X window, centred on the 6705. Press Diff Body B into Diff Body A (tight, fully
    seated), turning the Diff Gear Shaft until its 40T band enters the pulley's bore; the band passes the
    6705 dry, so no epoxy reaches the bearing. Through the window, set the pulley flush with both ends of
    the band before the epoxy cures.
14. Feed all 6 tool wires through Diff Body B: Red/White/Blue through the top entrance and out one side of the
    shaft; Black/Green/Yellow through the bottom and out the other side (only 3 fit per channel). Confirm the
    wires slide freely before continuing.
15. Feed the shaft wires through the assembled Split Gear and slide it down to meet Diff Body B.
16. Lightly sand one end of the 96 mm CF rod; epoxy the Diff End Pulley 6 mm from the tip, protruding side
    toward the rod's long side.
17. Confirm the 6703/MR128 bearings are seated so the shaft end protrudes ~1 mm past the 6703.
18. Super-glue and snap the Diff Axle Keeper over the shaft end, against the 6703.
19. Press the MR85 into the flat back of the Diff Gear Axle, ~1 mm proud. It seats by its **OD**, in the
    same Ø8 bore the rod runs in — the Ø5 bore is the race that leaves this subassembly.
20. Sand the other rod end and epoxy the Diff Gear Axle onto it. The rod **stops 1.5 mm short of that back
    face**, on the MR85, which leaves 12.5 mm of Ø8 lap for the joint. That is why step 19 comes first: a
    rod driven to the face leaves the bearing nowhere to go.
21. Insert the CF rod through the Diff Gear Shaft until it stops.
22. Hand-turn the Split Gear to confirm free rotation.
23. Slide one AS thrust race over the wires and Diff Body B shaft, then the AXK0819, then the second race.
    Epoxy only the chamfered edge of a Diff Keeper (apply sparingly with a nail), feed the wires through, and
    join to Diff Body B. **The keeper does not butt the Split Gear** — the stack stands between them, on
    the shaft, bearing on the Split Gear Top's base face. Expect ~2.4 mm of shaft still proud of the
    keeper once both are on ([DC-11(e)](009-Design-Completion.md#procurement-data)).
24. Clamp a second Diff Keeper on top of the epoxied one until cured.

## 008.7 End Arm Hub
Parts: [007.7](007-Bill-of-Materials.md#0077-end-arm-hub).

1. Insert a 6807 bearing into each Axis Intersection half.
2. Press the New Belt Pulley into the Arm-Body-side half.
3. Epoxy the holes on the Arm-Body-side Axis Intersection.
4. Epoxy the mirrored other half and join the two; epoxy the remaining holes for the 48 mm strakes.
5. Slide the 48 mm CF strakes in, wipe excess, clamp in 2 places, and cure — periodically spinning the New
   Belt Pulley to confirm it turns freely.
6. Epoxy the 3 81 mm CF strakes into the Internal Inner Pulley slots, flush with the face; keep the flush
   side clean.
7. Press 2 6703 into one side of the New Belt Pulley and 1 into the other; seat fully.
8. Align the End Arm Hub's 4 back holes with the 4 nubs on the assembled New Belt Pulley and push together.
9. Slide the Internal Outer Pulley onto the 113 mm stainless rod, set screws toward the rod's long end, and
   lock 3.1 mm from the end; tighten set screws incrementally and evenly.
10. Slide a Pulley Spacer between the Internal Inner and Outer Pulleys and join them.
11. Feed the rod/pulley through the End Arm Hub connection as far as it goes.
12. Prepare 4× M3 × 107 mm all-thread: thread on 2 M3 nuts and 1 washer at one end, flush.
13. Place the End Arm Code Disk on the outside of the Axis Intersection hub, raised side in.
14. Thread one rod into the End Arm Hub until it protrudes slightly through the code disk; add an M3 washer
    and jam nut.
15. Add a second washer and jam nut with threadlocker, flush with the rod end. The External Inner Pulley must
    clear all 4 jam nuts and rods — a standard M3 nut is too thick and will foul the pulley.
16. Epoxy 3 M3 nuts into the Internal Outer Pulley slots and 3 into the External Outer Pulley slots; cure.
17. Thread 6 M3 × 6 mm set screws into the epoxied nuts, flush with the nut ends.
18. Break the connection between the paired end nuts on each rod, add an M3 washer, and snug the inner nut
    without over-tightening.
19. Snap the End Arm Hub Cap into place.
20. Press one MR128 into the Internal Outer Pulley end and another into the End Arm Hub Cap.
21. Slide the External Inner Pulley onto the stainless rod until it stops.
22. Add the second Pulley Spacer, then the External Outer Pulley.
23. Tighten the 3 External Outer Pulley set screws, applying pressure from both sides while tightening evenly.
24. Press 2 MR128 into the Front Panel shaft hole (relieve the first print layer if the bearings distort or
    crack the opening).
25. Seat the Front Panel's bottom saddle onto the Arm Body protrusion, over the stainless rod shaft.
26. Epoxy the concave inner face of a Diff Keeper and join it to the Front Panel.

## 008.8 External Gear
Parts: [007.8](007-Bill-of-Materials.md#0078-external-gear). Builds the 3rd strain-wave drive (J3) — follow
[008.3](#0083-harmonic-drive-motors) steps 1–11 for the drive, then the steps below.
[009.1 § 3.3](009.1-Performance-Characterization-Protocol.md#test-33-j3-drive-stack) is taken between steps 6
and 13, while the drive is open.

1. Place 4 M3 nuts into the hex nut holders on the Ex Gear Motor End Cap.
2. Screw M3 × 10 mm bolts into those nuts from the underside.
3. Feed the motor wires through the End Cap.
4. Epoxy the motor bottom and End Cap top and join, aligning the notch with the wire exit; then pull the
   bolts away from the End Cap so the nuts seat inward.
5. Press one 6810 ~38 mm into the External Gear; press the second 6810 into the top. The upper one's inner
   race runs free on the Flex Spline Attach's land.
6. Replace the temporary bolts one at a time with M3 × 12 mm socket-head bolts and #6 washers, cross-pattern.
7. Mount the strain-wave top in the Ex Gear Stator Holder ([008.3](#0083-harmonic-drive-motors) step 12).
8. Slide the Ex Gear Stator Holder onto the External Gear, its eight keys in the gear's slots, pressing while
   rotating the shaft until the keys bottom in the slots.
9. Place M3 nuts into Nut Holder A/B, slide into the Ex Gear Mount (curvature sets orientation), seated to
   accept the all-thread.
10. Feed the motor wires through the Ex Gear Mount hole, slide onto the strake holes, press hand-tight.
11. Install 4× M3 × 12 mm socket-head bolts to secure the External Gear.
12. Thread 2 M3 nuts onto one end of an M3 × 46 mm all-thread, tightened together.
13. Press a 6810 into the Ex Gear Mount Top's bearing seat from the underside until it stops on the seat's
    shoulder. Fit the Mount Top over the External Gear, insert the all-thread, and tighten.
14. Install the angle and rotate motors: feed each shaft back to front through the mount, wires toward the arm
    shaft.
15. Place M3 washers on 4× M3 × 8 mm bolts, insert through the mount front, tighten cross-pattern until each
    motor seats fully (no aluminum body exposed) — do not over-tighten the aluminum receivers.

## 008.9 Belts
Parts: GT2 belts/pulleys from [007.7](007-Bill-of-Materials.md#0077-end-arm-hub) and
[007.8](007-Bill-of-Materials.md#0078-external-gear). Belt lengths are derived rather
than measured ([007.1 § 3](007.1-Parts-Catalog.md#3-belts-and-pulleys)), and the driven pulleys are
printed from `config="revised"` ([DC-12](009-Design-Completion.md#wrist-pulley-rework)).

⚠️ **Count the pulley teeth before fitting the belts** and check them against the specified train in
[004 § Wrist](004-Mechanical-Architecture.md#wrist-and-differential-j4j5). Parts carrying the previous
version's counts — what `config="previous"` builds — scale every commanded wrist angle by 2.4. Verify J4/J5 resolution empirically after
calibration regardless.

1. Slide the 2 16T × 5 mm GT2 pulleys onto the external motors.
2. Before tightening the set screws, confirm the belts line up with the belt directors above.
3. Tighten one set screw against the flat of each motor shaft.
4. Fit the two 1140 mm belts to the External pulleys and the two 940 mm belts to the differential inputs.
   Confirm each against its measured centre distance before committing — 20 mm of belt is 10 mm of centre
   distance, so a wrong length is not tensionable.

## 008.10 Wire Harness
Parts: [007.10](007-Bill-of-Materials.md#00710-wire-harness). Uses the previous version's Motor Control Board
([DC-7](009-Design-Completion.md#motor-control-pcb)).

1. Snip the M2 connection on the back of the Motor Control Board to break it.
2. Place the FPGA (MicroZed) board on the Motor Control Board and snap in.
3. Slide the microSD into the FPGA board until it locks (press again to release).
4. Align the PCB spacers with the bolt holes; feed 4× M3 × 20 mm bolts through the FPGA board, spacers, and
   out the back of the Motor Control Board.
5. Epoxy the bottom PCB bracket 37.5 mm up from the Arm Body joint — this sets the top bracket position too.
6. Hold the Motor Control Board with the brackets on the opposite side of the 1" CF tube and screw in the
   M3 × 20 mm bolts without over-tightening (an M3 nut can back up a stripped hole).
7. Fit exactly one opto-supply jumper — `W1` or `W2` — before any opto board is connected
   ([005 § Boards](005-Electronics-and-Control.md#boards)).
8. Land each stepper and each opto board on the header its **joint name** selects, not its connector
   number — the two orders differ, and the map is in
   [005 § Boards](005-Electronics-and-Control.md#boards).
9. **Power inlet.** Land the 18 AWG pair on the `KPJX-PM-4S` receptacle: red to pins 1 and 4, black to
   pins 2 and 3 — both pins of each polarity, per [005 § Power](005-Electronics-and-Control.md#power).
   Mount the receptacle in its cut-out — which part carries that cut-out is open
   ([DC-14](009-Design-Completion.md#power-inlet-mounting)) — then connect the other end to `J24`: black to
   negative (−), red to positive (+).
10. **Tool-interface wiring:** land all six conductors as
    [005 § Tool interface wiring](005-Electronics-and-Control.md#tool-interface-wiring) specifies. Confirm
    the White wire on `J24` pin 2 before first power-on — the cross-version hazard it guards against is
    specified there.

## 008.11 Tool Interface / Gripper
Parts: [007.11](007-Bill-of-Materials.md#00711-tool-interface--gripper).

1. Dry-fit the 25 mm CF strake in the Span Mount's triangular top slot.
2. Epoxy the 25 mm strake into the Span Mount slot until its top is flush with the Span Mount notch and flush
   with the inner surface at the bottom.
3. Slide 3 M3 nuts into the Tool Interface Body outer slots, align by threading M3 × 10 mm bolts into the 3
   outer holes, then force a little epoxy into the holes above the nuts to lock them.
4. Press 2 6703 bearings into each side of the Roll Body.
5. Clip the head off a 1" #19 satin pin, chuck it, and ream the 4 smallest holes on the bottom of the Roll
   Driver.
6. Push 4 satin pins through the reamed holes ~6 mm proud, cut the heads, super-glue flush, trim and sand
   smooth.
7. Thread the 4 M2 × 20 mm bolts into the Roll Driver, leaving 2 diagonally-opposite bolts ~2 mm proud to
   engage the Span Mount holes.
8. Press the Roll Driver's flat side into the non-flat side of the Roll Body, flush with the far 6703 (tap
   gently if needed).
9. Identify the two servos (labeled 1 and 3); move the connector from motor 1 into motor 3.
10. Press the connectors into the groove on each motor's top edge and slide each motor into the Tool
    Interface Body until it snaps.
11. Mark the 3-pin connector with a sharpie: blue = data (left), red = power (middle), black = ground
    (right), viewed from the front (M3 × 10 mm bolt facing you); the opposite-side connector is mirrored.
12. Cut the 3 wires mid-connector on the right side (removing the top connector portion), feed them through
    the motor's middle hole toward the top of the body, and tin the ends.
13. Trim each wire to ~13 mm and strip ~6 mm.
14. From the front, the topmost servo wire is ground → black pin; middle is power → red; bottom is data →
    blue. The opposite side is mirrored.
15. Heat-shrink each connection as you solder it.
16. Feed 4× 25 cm lengths of 28 AWG (black, red, blue, green) through the Roll Driver center hole and press
    into the Span Mount groove.
17. Align and tighten the Roll Driver bolts into the Span Mount, keeping the wires seated, until slightly
    proud.
18. Thread an M2 washer and M2 nut onto each (use a flathead/hobby knife to spin the nut), holding while
    tightening.
19. Remove the motor-cap bolt **without turning the motor** (turning misaligns zero and forces a reset).
20. Feed the Roll Body wires into the motor's center hole without turning the motor; pull through until the
    Roll Driver nearly contacts the motor, matching the drive nubs near zero (Span Mount nubs on top at
    zero; the Span Mount Eye reads 90° when the Roll Body is pushed on).
21. Gently push the Roll Driver into the motor, rocking the Span Mount to confirm engagement.
22. Thread 2 M2 × 12 mm bolts into the Roll Body end holes with M2 nuts (leave the center empty).
23. Thread 4 M2 × 16 mm bolts through the remaining holes with M2 washers.
24. On the Span Motor (#1), remove the center screw and its plastic driver.
25. Align the motor driver with the Span Mount hole and push into the 2 nubs at the Span Mount base.
26. Fasten with 2 M2 × 12 mm bolts (right of the Span Mount), M2 washers, and M2 nuts.
27. Solder the Roll Motor's remaining connector with the same color scheme, then feed the 3 wires through the
    right servo hole toward the top of the body.
28. Trim to ~13 mm, strip ~6 mm; map top-to-bottom ground/power/data, this side mapping to blue/red/black
    directly.
29. Slip 1/4" heat-shrink over the black, red, blue wires exiting the body.
30. Solder matching colors, slide heat-shrink over each joint, and shrink.
31. Plug the cut-off connector into the back of the Span Motor; trim and solder the remaining wires.
32. Solder the original first connector's end to the Span Motor feed wires before connecting the Roll Motor;
    pull the joint taut away from the Span Motor first.
33. Repeat solder/heat-shrink for the remaining pairs.
34. Super-glue the wires exiting the Tool Interface base so Span Mount rotation cannot snag them.
35. Power the motors briefly to confirm they turn and their LEDs light.
36. Align the notch inside the Span Driver's bore with the motor's driver key.
37. Push the Span Driver into place and secure with an M2.6 × 10 mm bolt, snug (over-tightening strips the
    mount).
38. Clip a 1" #19 satin pin, chuck it, and ream the 2 small holes atop the Pinion Gear.
39. Super-glue satin pins into the reamed holes with needle-nose pliers, cure, trim flush, sand.
40. Place an M3 nut in the Pinion Gear.
41. Press the remaining 2 MR128 bearings into both sides of the Static Finger.
42. Slide the Pinion Gear into the Static Finger, horseshoe cutout toward the opening.
43. Align the Pinion Bearing EXT with the short hash mark on the Pinion Gear (fits one way) and secure with an
    M3 × 16 mm bolt, loose enough to still turn freely.
44. Turn the Span Driver until its flat faces forward, horseshoe toward you — the gripper's open position.
45. Turn the Pinion Gear until the Pinion Bearing EXT hash aligns with the long hash on the Static Finger.
46. Push the Static Finger onto the Span Mount so the 25 mm strake seats into its Span Mount hole.
47. Slide the Dynamic Finger into the Static Finger and close fully.
48. Cut two yoga-mat pieces to the finger inside faces and hot-glue them as grip pads.

## 008.12 Firmware Configuration and Calibration
Config: [006-Firmware-and-Calibration.md](006-Firmware-and-Calibration.md). Required before first use on a
from-scratch build.

1. Set `Defaults.make_ins` per [006](006-Firmware-and-Calibration.md#firmware-defaults-defaultsmake_ins) —
   the `AxisCal`/`Interpolation` values (already the active defaults) and the correct `LinkLengths` for the
   physical build.
2. Determine whether this build needs calibration, per the policy in
   [006 § Calibration model](006-Firmware-and-Calibration.md#calibration-model). A **from-scratch build**
   runs the full [factory calibration procedure](006-Firmware-and-Calibration.md#factory-calibration-procedure);
   a build reusing an already-calibrated unit's electronics does not. This is the one step hardest to
   recover from if done wrong — read that section before starting.
3. Configure `RunDexRun` per [006](006-Firmware-and-Calibration.md#factory-calibration-procedure) step 3.10
   so the robot finds home and starts PhUI on boot.
4. Power-cycle and confirm the boot sequence completes as specified in
   [006 § Boot and PhUI](006-Firmware-and-Calibration.md#boot-and-phui).

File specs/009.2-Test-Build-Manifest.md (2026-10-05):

# 009.2 — Test Build Manifest

This document specifies the unit that [009.1](009.1-Performance-Characterization-Protocol.md) is run on:
what it contains, what it deliberately leaves out, the order it is assembled in, and which open item each
stage answers. It **selects** from the bill of materials rather than restating it — each stage names the
[007](007-Bill-of-Materials.md) subassembly it draws and states only what differs from a baseline build.

## The minimum build is nearly the whole robot

Reach, repeatability, payload and speed are properties of the assembled arm: they cannot be measured on a
subassembly, a rig, or a partial kinematic chain. Of everything
[009.1](009.1-Performance-Characterization-Protocol.md) measures, only the fan rail and the two
during-assembly readings come off partial hardware. **The test build is therefore the baseline build minus
the exclusions below**, staged so that each stage answers what it can before the next one is committed.

What the staging buys is not a smaller build but an earlier answer: a board that does not drive a motor is
worth discovering before 108 parts are printed, and a belt ordered before its centre distance is measured
is ordered twice.

## Gate items — close these before cutting anything

One item is a prerequisite rather than an output, and the build works around it.

| Gate | Why it gates | If it is not closed first |
|---|---|---|
| [DC-14](009-Design-Completion.md#power-inlet-mounting) — the inlet's mounting home | The receptacle is panel-mount and the design has no panel | Deferrable only: the test build takes bench leads to `J24` instead (Stage 1). The test build does not close this item |

The wrist pulleys ([DC-12](009-Design-Completion.md#wrist-pulley-rework)) and the joint between the L3
tube and the differential ([DC-11(h)](009-Design-Completion.md#procurement-data)) are closed. Print every
wrist pulley from `config="revised"`, whose counts match `AxisCal`
([006](006-Firmware-and-Calibration.md#drive-constants-axiscal)). Stage 4 measures the L3 lap on the built
arm.

## Stage 0 — Desk work, procurement, print tuning

Nothing here needs a robot, and everything downstream waits on it.

1. **Close the three authoring gates** above. DC-14 stays open and is worked around.
2. **Order the strain-wave sets on day one.** Three sets of [C-201](007.1-Parts-Catalog.md#c-201--521-strain-wave-component-set)
   are the longest-lead purchase in the build by a wide margin
   ([009 § Strain-wave component set](009-Design-Completion.md#strain-wave-component-set)); every other bought
   part can be had inside a week. Ordering them last turns a two-month build into a five-month one.
3. **Start board fabrication.** The Motor Control Board and the five optical boards
   ([005 § Boards](005-Electronics-and-Control.md#boards)) are fabricated from the gerbers in the hardware
   repository, not bought. Order **spare optical boards** — they are small and cheap, and one dead board
   with the arm closed up costs a joint and a teardown.
4. **Buy the remainder** of [007.1](007.1-Parts-Catalog.md), less the two gated purchases below.
5. **Qualify the machine on the fit coupon before committing the part set.** Print the coupon
   [007.2 § Print fits](007.2-Printed-Parts.md#print-fits) specifies, and adjust the two print-fit
   clearances until every fit on it passes. Then hold every setting for the whole run and record it
   against [DC-11(d)](009-Design-Completion.md#procurement-data). Two coupons cost an hour; a mis-set wall
   count costs the print list twice.

### Purchases deliberately held back

| Held | Released by | Why it cannot be ordered yet |
|---|---|---|
| Wrist and elbow belts | Stage 4, via [009.1 § Test 2.2](009.1-Performance-Characterization-Protocol.md#test-22-belt-centre-distances) | Belt length follows from the centre distance the built arm actually presents, and the specified lengths are provisional. Measure, then order |

*The cooling fan is no longer held back: [C-716](007.1-Parts-Catalog.md#7-electronics-and-wiring) spans
every rail the board can present, so it is ordered with the rest of [007.1](007.1-Parts-Catalog.md) and the
`J23` reading in [009.1 § Section 5](009.1-Performance-Characterization-Protocol.md#section-5-fan-rail-measurement)
confirms rather than selects it.*

## Stage 1 — Bench electronics

The whole control chain, on the bench, with no mechanics attached.

**Draws:** Motor Control Board, FPGA module and one optical board with its emitter and detector
([005 § Boards](005-Electronics-and-Control.md#boards)); the DC supply; one stepper; one printed code disk
to pass through the optical gap; bench leads to `J24`.

**Assemble:** fit exactly one opto-supply jumper. Deploy the firmware and set the serial number per
[006 § Step 1](006-Firmware-and-Calibration.md#step-1--deploy-files-and-set-serial-number). Bring the
board up under the power-on test in [009 § Motor Control PCB](009-Design-Completion.md#motor-control-pcb).

**Answers:** the board-level part of [DC-7](009-Design-Completion.md#motor-control-pcb) — jumper state and
rail voltages — and [Section 5](009.1-Performance-Characterization-Protocol.md#section-5-fan-rail-measurement),
which confirms the rail the fan runs on. The per-joint half of DC-7 waits for Stage 5.

**Exit gate:** every driver channel steps the test motor when the motor is moved to that channel's
connector; the boost and buck rails hold their specified values ([005 § Power](005-Electronics-and-Control.md#power));
the optical channel's output changes as the code disk passes; the `J23` rail is recorded and falls inside
the fan's operating span.

⚠️ Do not skip this stage on the argument that the board is a known design. It is a **fabricated** board
from recovered gerbers, and this is the only point in the build where it is accessible from both sides.

## Stage 2 — Base and shoulder stack

**Draws:** [007.2 Base](007-Bill-of-Materials.md#0072-base),
[007.3 Harmonic Drive Motors](007-Bill-of-Materials.md#0073-harmonic-drive-motors),
[007.4 Main Pivot](007-Bill-of-Materials.md#0074-main-pivot), and the base mounting plate stock
[C-509](007.1-Parts-Catalog.md#c-509--base-mounting-plate-stock).

**Assemble:** build the glue rigs ([008.1](008-Assembly.md#0081-glue-rig-assembly)) first — every bonded
carbon-fibre member in the robot passes through them — then
[008.2](008-Assembly.md#0082-base), [008.3](008-Assembly.md#0083-harmonic-drive-motors) and
[008.4](008-Assembly.md#0084-main-pivot).

**Answers:**

- [DC-13](009-Design-Completion.md#base-height-and-l1)'s confirmation: the assembled stack gives the
  mounting-face-to-J2-axis dimension via [Test 3.1](009.1-Performance-Characterization-Protocol.md#test-31-mounting-face-to-j2-axis).
- [DC-11(a)](009-Design-Completion.md#procurement-data) — the stepper is specified, and what this stage
  confirms is its **48 mm body**. The end cap is a fixed datum, so body length decides where the whole drive
  sits in the joint; record how much all-thread adjustment the Stator Holder needs to take up, since that is
  the stack-up band nothing in the design record states. Measure it on the first joint, before three of them
  are buried in the arm.
- [DC-11(d)](009-Design-Completion.md#procurement-data) — the first substantial print run either holds the
  Stage 0 coupon's fits at scale or it does not.

**Exit gate:** Test 3.1 passed; J1 and J2 each turn by hand across their travel with
no binding and no detectable output-side lash beyond what the strain-wave set contributes.

## Stage 3 — Differential subassembly

Built and checked on the bench, off the arm, where the wrist is still reachable from every side.

**Draws:** [007.6 Differential](007-Bill-of-Materials.md#0076-differential) in full, including the
fabricated CF strakes and rod, the thrust bearing stack and the finishing-nail locking dowels.

**Assemble:** [008.6](008-Assembly.md#0086-differential).

**Answers:**

- [Test 1.1](009.1-Performance-Characterization-Protocol.md#test-11-j4-and-j5-travel) by hand, before the
  wrist is ever driven. A differential that cannot reach its specified travel is a mechanical fault, and
  finding it now costs one subassembly rather than a stripped arm.
- [DC-11(e)](009-Design-Completion.md#procurement-data) — assembling from the full parts list is what
  determines whether every modelled part has somewhere to go. Note any part the procedure never calls for,
  and any step that calls for a part the list does not carry.

**Exit gate:** J4 and J5 each sweep their specified travel; the parts list is fully consumed or every
leftover is accounted for; no part was forced.

## Stage 4 — Arm through to the wrist, dry

The arm is closed structurally but **no belts are fitted** — their length is not known yet.

**Draws:** [007.5 Arm Body](007-Bill-of-Materials.md#0075-arm-body),
[007.7 End Arm Hub](007-Bill-of-Materials.md#0077-end-arm-hub),
[007.8 External Gear](007-Bill-of-Materials.md#0078-external-gear),
[007.9 External Gear Mount + Differential Motors](007-Bill-of-Materials.md#0079-external-gear-mount--differential-motors).

**Assemble:** [008.5](008-Assembly.md#0085-arm-body), [008.7](008-Assembly.md#0087-end-arm-hub),
[008.8](008-Assembly.md#0088-external-gear).

**Answers:** [Test 3.3](009.1-Performance-Characterization-Protocol.md#test-33-j3-drive-stack), while
[008.8](008-Assembly.md#0088-external-gear) has J3's drive open, and
[Test 2.2](009.1-Performance-Characterization-Protocol.md#test-22-belt-centre-distances), which releases the
belt order. The belt directors are no longer a question of *type*
([DC-11(c)](009-Design-Completion.md#procurement-data)); what fitting them still tests is whether a printed
Ø8.000 shank takes the MR128 bore, which is the print profile's business.

**Exit gate:** Test 3.3 passed; J3 turns by hand across its travel with no binding; both centre distances
recorded and the belts ordered. Expect a wait here; it is the reason
Test 2.2 sits this early in the protocol rather than alongside the other belt work.

## Stage 5 — Belts, harness, tool interface

**Draws:** the belts ordered at Stage 4; [007.10 Wire Harness](007-Bill-of-Materials.md#00710-wire-harness);
[007.11 Tool Interface / Gripper](007-Bill-of-Materials.md#00711-tool-interface--gripper); the fan and
bracket.

**Assemble:** [008.9](008-Assembly.md#0089-belts), [008.10](008-Assembly.md#00810-wire-harness),
[008.11](008-Assembly.md#00811-tool-interface--gripper).

**Answers:** the per-joint half of [DC-7](009-Design-Completion.md#motor-control-pcb) — with the harness
landed, each joint can be commanded and watched for its own encoder responding. Run
[Test 1.2](009.1-Performance-Characterization-Protocol.md#test-12-tool-conductors-through-the-wrist) while
the tool conductors are being dressed through the wrist, and repeat it at Stage 6 with the wrist driven
rather than turned by hand.

**Exit gate:** all five arm joints step under firmware command and each reports motion on its own encoder;
six conductors are continuous from the board to the tool connector; both tool servos answer on the bus.

## Stage 6 — Calibration, then characterization

**Assemble:** nothing further. Run the factory calibration procedure end to end
([006](006-Firmware-and-Calibration.md#factory-calibration-procedure),
[008.12](008-Assembly.md#00812-firmware-configuration-and-calibration)). Steps 2 and 3 are run from the two
calibration job files [DC-10](009-Design-Completion.md#from-scratch-calibration-files) inventories, and
running them to completion here is what closes that item. Neither has been run since it was restored, so
budget this stage for debugging the calibration as well as performing it.

**Answers:** everything remaining in [009.1](009.1-Performance-Characterization-Protocol.md) — the code-disk
check, L4 from Cartesian residual, base rigidity, and the whole performance envelope. These are the
measurements that need a *calibrated* arm, which is why they are last and why no amount of staging can
pull them earlier.

**Exit gate:** [009.1 § Section 7](009.1-Performance-Characterization-Protocol.md#section-7-closing-out) is
worked through and each result is written into the document that owns it.

## What each open item is waiting for

| Open item | What answers it | Stage |
|---|---|---|
| [DC-7](009-Design-Completion.md#motor-control-pcb) — Motor Control PCB | Jumper state and rail voltages on the bench; then each joint stepping with its own encoder responding | 1, then 5 |
| [DC-9](009-Design-Completion.md#performance-characterization) — Performance characterization | [009.1](009.1-Performance-Characterization-Protocol.md) run in full | 1–6 |
| [DC-10](009-Design-Completion.md#from-scratch-calibration-files) — Calibration job files | Steps 2 and 3 run to completion, and a `post_cal_info.JSON` that homes correctly | 6 |
| [DC-11(a)](009-Design-Completion.md#procurement-data) — Stepper body length | 48 mm, read as the drive's axial stack-up on a built joint | 2 |
| [DC-11(d)](009-Design-Completion.md#procurement-data) — Print parameters | The fit coupon, then held across the production run | 0, confirmed at 2 |
| [DC-11(e)](009-Design-Completion.md#procurement-data) — Model-versus-BOM mismatches | Building from the list and recording what is left over or called for but absent | 3, and every stage |
| [DC-11(h)](009-Design-Completion.md#procurement-data) — L3 far-end joint | Closed by analysis; the build confirms it, C-505 sliding 15.000 mm over Diff Body A's spigot with 6.000 mm left proud | 4 |
| [DC-12](009-Design-Completion.md#wrist-pulley-rework) — Wrist pulley rework | Closed by authoring; the tooth count on each printed pulley ([008.9](008-Assembly.md#0089-belts)) | 5 |
| [DC-13](009-Design-Completion.md#base-height-and-l1) — Base height and L1 | Closed by analysis; the build confirms L1 via [Test 3.1](009.1-Performance-Characterization-Protocol.md#test-31-mounting-face-to-j2-axis) and J3's drive stack via [Test 3.3](009.1-Performance-Characterization-Protocol.md#test-33-j3-drive-stack) | 2, 4 |
| [DC-14](009-Design-Completion.md#power-inlet-mounting) — Power inlet mounting | Authoring. **This build does not close it** — it is worked around | — |

## What the test build leaves out

The baseline build already excludes cosmetic covers and alternate end effectors — see
[007.2 § Not in the build list](007.2-Printed-Parts.md#not-in-the-build-list). The test build omits two
further things:

| Omitted | Reason |
|---|---|
| Wire Entry, `#800-001` / `#800-002` | No assembly step places them and their role depends on how [DC-14](009-Design-Completion.md#power-inlet-mounting) resolves. Printing them now risks printing the wrong part; the test build takes power in on bench leads instead |
| Gripper fingers and grip pads | The tool-bus and conductor checks exercise the interface body and the roll and span axes. The fingers add nothing a measurement depends on, and can be built later without disturbing anything |

Everything else in [007](007-Bill-of-Materials.md) is required. Resist trimming further: a subassembly
left out of a characterization build silently changes the mass, the stiffness, or the harness routing that
the measurement is supposed to capture.

## Additions that exist only for the test build

| Addition | Purpose |
|---|---|
| Bench supply on leads direct to `J24` | Stands in for the unmounted power inlet. Deliver the supply specified in [005 § Power](005-Electronics-and-Control.md#power) — the substitution is mechanical, not electrical |
| Print fit coupon | Stage 0 print-parameter tuning. Not a robot part and not printed again afterwards |
| Spare optical boards | One failure otherwise costs a teardown |
| Instruments | Listed in [009.1 § Instruments](009.1-Performance-Characterization-Protocol.md#instruments) |

## Recording what the build tells you

[009.1 § Section 6](009.1-Performance-Characterization-Protocol.md#section-6-recording-template) carries the
template for measured values, and [§ Section 7](009.1-Performance-Characterization-Protocol.md#section-7-closing-out)
routes each one to the document that owns it.

Stages 0 through 5 additionally produce findings that are not measurements — a motor that seated or did
not, a part with nowhere to go, the print settings that held. **Write these down at the bench, against the
DC item in the table above, as they happen.** They are the answer to roughly half the open items in
[009](009-Design-Completion.md), they exist only as an observation at the moment they occur, and a stage
later the evidence is inside a closed assembly.

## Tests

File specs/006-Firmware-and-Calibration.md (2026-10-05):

# 006 — Firmware and Calibration

This document specifies the firmware configuration and the calibration model of Dexter: the
`Defaults.make_ins` parameters that describe the physical robot to the firmware, the drive constants, and
the factory calibration and bring-up procedure. It is a **derived artifact** — its values follow from the
kinematics ([003](003-Kinematics.md)) and electronics/control ([005](005-Electronics-and-Control.md)) design
and must be regenerated when those change. Values here are traceable to the firmware file and the factory
calibration documentation; what remains open is listed in [009](009-Design-Completion.md).

## Firmware defaults: `Defaults.make_ins`

`Defaults.make_ins` describes the physical robot to the DexRun firmware and sets default operational values;
it is the firmware configuration of record:

```
; AxisCal is the gear ratio times the steps per revolution times the microstepping mode
; e.g. for a 52:1 drive with a 400 step motor in 16x microstepping: 52*400*16 = 332800
S, AxisCal, -332800, -332800, -332800, -86400, -86400 ; Dexter HDI

; Interpolation factor for each joint
S, Interpolation, 1, 1, 1, 1, 1 ; Dexter HDI

; Length of each link, in microns. L5 is first, L1 last.
S, LinkLengths, 82440, 39500, 307500, 339092, 231500;

; Joint motion limits, in arcseconds from center
S, J1BoundryHigh, 684010;   S, J1BoundryLow, -684010;
S, J2BoundryHigh, 350010;   S, J2BoundryLow, -350010;
S, J3BoundryHigh, 570010;   S, J3BoundryLow, -570010;
S, J4BoundryHigh, 390010;   S, J4BoundryLow, -390010;
S, J5BoundryHigh, 684010;   S, J5BoundryLow, -684010;

; Maximum torque for tool servos (roll, span)
S, ServoSet2X, 1, 35, 1020; Roll goal torque
S, ServoSet2X, 3, 35, 1020; Span goal torque
```

*Source: `Firmware/Defaults.make_ins`.* Link lengths and joint boundaries are specified in
kinematic terms in [003](003-Kinematics.md#link-lengths) and [003](003-Kinematics.md#joint-travel-limits).
The previous version's values are retained (commented) in the source file for reference; the deltas are the design
changes described in [001](001-Overview.md#5-design-lineage).

⚠️ **`LinkLengths` above differs from the shipped file in two fields.** The file as published carries
`59500` for L4 and `235200` for L1; the block above carries the specified **39500** and **231500**
([003 § Link lengths](003-Kinematics.md#link-lengths)). Write those values into `Defaults.make_ins` before
first Cartesian motion: the onboard `M`, `T` and `C` kinematics all consume the line, DDE reads the same
line from the robot, and an error in any link length displaces every commanded Cartesian position. `a`/`P` joint moves
are unaffected.

## Drive constants (`AxisCal`)

`AxisCal` is the per-joint conversion between motor steps and joint angle:
`AxisCal = gear_ratio × motor_steps_per_rev × microstepping`.

| Joints | Value | Derivation | Net reduction | Meaning |
|---|---|---|---|---|
| J1, J2, J3 | −332800 | 52 × 400 × 16 | **52:1** | Strain-wave base joints, 0.9°/step (400-step) motor at 16× microstepping. **Identical to the previous version** — the base-joint reduction is unchanged. |
| J4, J5 | −86400 | 13.5 × 400 × 16 | **13.5:1** | The wrist is resolved through a **physical pulley reduction**, not microstep oscillation. |

- **`Interpolation`** = 1 for all joints. The previous version used 16 on J4/J5 to sub-divide microsteps for the
  oscillation trick; 1 is correct here because the belt reduction supplies wrist resolution physically.
- **The net wrist reduction *is* derivable — 13.5:1.** `AxisCal = gear_ratio × 400 × 16`, so
  86400 / 6400 = **13.5:1**. What the firmware alone does not pin is how that ratio is decomposed into
  tooth counts; the belt stages that realize it are specified in
  [004 § Wrist](004-Mechanical-Architecture.md#wrist-and-differential-j4j5). ⚠️ **Confirm the as-built
  wrist ratio before first motion** — the printed model set does not yet carry the specified counts, and
  what running this `AxisCal` against parts printed as modelled would do to every commanded J4/J5 angle is
  stated there.

*Source: `Firmware/Defaults.make_ins`, `Firmware/AxisCal.txt`; wiki `Hardware.md`, `Joints.md`, `Firmware.md`,
`set-parameter-oplet.md`.*

> **AxisCal.txt vs Defaults.make_ins — base-joint note.** `AxisCal.txt` is a derived runtime file
> (`−(gear_ratio × microstep × steps) / 1 296 000` per joint, plus a trailing `ANGLE_END_RATIO` term
> `−round(ratio_J4 / ratio_J3 × 2²⁴)`). The copy in this repo encodes **50:1** on J1–J3 (line value
> −0.24691 = 50, and the trailing term −4 529 848 = −round(13.5 / 50 × 2²⁴)), while `Defaults.make_ins`
> and the physical component set specify **52:1**. `Defaults.make_ins` (52:1) is authoritative; the
> sampled `AxisCal.txt` appears stale/mis-generated and **must be regenerated to 52:1 on a real build** (a
> 50:1 file would give ≈4 % base-joint scale error). Both files agree J4/J5 = 13.5:1.

## Motion shaping parameters

`MaxSpeed`, `StartSpeed`, `Acceleration` and `CartesianSpeed` shape every move
([003 § Motion commands](003-Kinematics.md#motion-commands)). They are **not** in `Defaults.make_ins`: they
are set at runtime by `S` commands, and a job file that needs a particular speed sets it there — the
calibration sweep in `Firmware/Cal.make_ins` is the worked example.

⚠️ **The `S, MaxSpeed` argument is not in arcseconds per second.** It is scaled by
`arcsec_per_nbits` = 0.4642324678861586 on the way in, a legacy unit retained for compatibility with
DDE's `_nbits_cf` form. A value read as arcsec/s overstates the commanded speed by a factor of ≈ 2.15.

| Parameter | Argument unit | Firmware default | As set by `Cal.make_ins` |
|---|---|---|---|
| `MaxSpeed` | 0.46423 arcsec/s per count | 108 000 arcsec/s (30 °/s) | 300 000 ⇒ ≈ 139 270 arcsec/s (≈ 38.7 °/s); 280 000 ⇒ ≈ 130 000 arcsec/s (≈ 36.1 °/s) for the calibration sweep |
| `StartSpeed` | same | 3 600 arcsec/s (1 °/s) | — |
| `Acceleration` | 6-bit FPGA field, 0–63, dimensionless | 3 | — |
| `CartesianSpeed` | microns per second | 300 000 µm/s (0.3 m/s) | — |

`CartesianSpeed` applies to the straight-line `T` and `C` moves, which derive each segment's joint speed
from the commanded tip speed; the joint-space `a` and `P` moves take `MaxSpeed` directly. The achieved
rates against these settings are measured on a build
([009.1 § 4.4](009.1-Performance-Characterization-Protocol.md#test-44-maximum-speed)).

*Source: `Firmware/DexRun.c` (`arcsec_per_nbits`, `maxSpeed_arcsec_per_sec`, `CartesianSpeed`, and the
`Params` table's `MaxSpeed`/`Acceleration` cases); `Firmware/Cal.make_ins`.*

## Encoder velocity monitor

`monitorTorque()` converts each joint's raw encoder word to a position it differences for velocity, and
faults the robot when the difference exceeds that joint's limit. The conversion is the ratio of two
per-joint arrays, `joints_corr[i] / joints_slots[i]`, and **the pair is fitted empirically, not derived** —
`joints_corr` is a tuned residual against whatever `joints_slots` it was tuned with. Neither term is
independently meaningful, so neither is corrected on its own.

This matters because `joints_slots` reads `{200, 184, 157, 115, 100}` while J2's code disk has **180** slots
([003 § Joint definitions](003-Kinematics.md#joint-definitions)); J2's monitor is therefore scaled 2.2 %
against its own joint. The trip has margin and the fault is a velocity limit rather than a position, so the
design of record keeps the fitted pair intact. Re-fit both terms together against measured J2 encoder
velocity if the monitor mis-trips on a build.

*Source: `Firmware/DexRun.c` (`monitorTorque`).*

## Calibration model

Dexter's precision depends on mapping each joint's raw optical-encoder readings to true joint position.
This mapping — the encoder **eye centers** and **index-pulse mapping** — is established once and **recorded
onto the specific robot** (`AdcCenters.txt`, `HiMem.dta`, `post_cal_info.JSON`). Once recorded, the mapping
removes the effect of imperfect code-disk slots, so the joint always returns to the exact commanded position
(REQ-CTL-6, REQ-PRE-1).

**Policy: a robot is calibrated at the factory and is not re-calibrated in the field.** Recalibration is
complex, the eye calibration affects the movement calibration, and there is no simple recovery if the
recorded values are overwritten incorrectly. Operationally:

- A **factory-built or already-calibrated unit** keeps its recorded calibration and is **not** recalibrated.
  Do not save calibration on such a unit.
- A **from-scratch build** (new opto boards, new code disks, new drives) has no recorded calibration and
  **must run the full factory procedure once** before first use — this is unavoidable for a new build and is
  the single most consequential bring-up step. The procedure is driven from two calibration job files, named
  in the steps below and inventoried in
  [DC-10](009-Design-Completion.md#from-scratch-calibration-files); running them on a build is what closes
  that item.

*Source: wiki `Encoder-Calibration.md`, `Dexter-Setup.md`; factory calibration PDFs.*

## Factory calibration procedure

For **from-scratch builds only.** Transcribed from the factory calibration documentation
(`DDE/InitialCalibration/HDI CAL INSTRUCTIONS- STEP {1,2,3}.pdf`). Requires WinSCP/PuTTY (or equivalent
SCP/SSH), DDE, and a grounded anti-static wrist strap whenever handling the FPGA board.

### Step 1 — deploy files and set serial number
1. Copy the factory file bundle onto the robot's SD filesystem via WinSCP (`Host 192.168.1.142`, user
   `root`). Change the default password on any unit exposed to an untrusted network.
   - `dde_apps/*` → `/srv/samba/share/dde_apps/`; `share/*` → `/srv/samba/share/`;
     `www/*` → `/srv/samba/share/www/`; `core/*` → `/root/Documents/dde/core/`
2. Power-cycle. Set the system clock via PuTTY (`date -s "<DDMonYY>"`).
3. Rebuild DexRun: `./pg` from `/srv/samba/share/` (a `gcc` compile of `DexRun.c`; benign
   `-Wstrict-aliasing` warnings are expected).
4. Edit `Defaults.make_ins` to set the six-digit **Dexter serial number** (printed on the Main Pivot) in
   place of the placeholder — this sets the MAC address and avoids LAN collisions between units. Power-cycle.

### Step 2 — per-joint eye calibration
1. Secure the robot with clearance for full rotation on every joint; remove the end effector's front part.
2. Align the "X" on the Base Long with the center of the ExGear Mount Bottom (J3 wire exit); fine-tune by
   aligning the J1 opto block's right edge with the raised notch on the Base Code Disk.
3. Move to the most upright (home) position; power on.
4. In DDE, open the calibration job file `DDE/InitialCalibration/Setup_Find_Index_Home_HDIv2.dde` →
   `Jobs → Calibrate Dexter…` → select the robot. Wait for the "Initializing…" dialog to clear (DDE has read
   `AdcCenters.txt`).
5. **Start with J2, not J1** — this order avoids over-rotating J2 into the work surface if J1/J2 wiring is
   swapped.
6. For each joint, adjust the two trim potentiometers until the plotted cycle is a centered,
   counter-clockwise circle (a clockwise cycle means the phototransistors are installed backwards — swap
   them). Center the eye and **Save**. Repeat for all 5 joints.
   - *Troubleshooting:* a cycle leaning to one side → opto block too far, move closer; a flattened/partial
     cycle → shim the opto block (start 0.05", add as needed); a cycle that won't center → phototransistor
     holes undersized, rework/replace the block.

### Step 3 — movement calibration and go-live
Every named routine below is a job defined in the Step 2 calibration file, run from its window.

1. Confirm the Step 2 base alignment; fresh reboot; open the calibration file.
2. `Undef` → `Clear` → `Eval`.
3. `Check_Eye_Order` — each row should show a clear largest-value pattern; a row breaking the pattern means
   that joint's eye needs revisiting (diode swap, disconnected opto wire, or off-center eye).
4. `Calibrate Optical Encoders` — moves each joint through its full range, recording index-pulse timing.
5. (Optional) verify smooth motion: `Dexter.set_Follow_Me()`, move each joint by hand, then
   `Dexter.set_Keep_Position()` and `OpenLoop`.
6. `Initial_Scan` — per joint, verify index-pulse (green) spike separation increases by 2 on each side of
   the 3 home (black) spikes, with no gaps within usable travel (a gap far from home is tolerable if the
   robot always powers on near home; a gap near home is not). `Save_Scan_Results`.
7. Power off; move to home (J1 at "X", others at visual zero); power on.
8. `Check_Eye_Order` → `Center_Eye` (await `Done`) → `Find_Idx_Eyes_Setup` (records
   `idx_eye_to_cal_offset`, small integers) → `Save_Eye_Offset` → `Find_Idx_Eyes_For_Cal`.
9. `Calibrate Optical Encoders` again → `post_cal_info` (writes `post_cal_info.JSON` — the artifact that
   makes "no recalibration needed" real) → `Check_Eye_Order` → `Find_Idx_Eyes` (confirm correct home
   return).
10. Enable boot jobs: in `/srv/samba/share/RunDexRun`, remove the leading `#` from the home-finding line
    (`dde_apps/Find_Index_Pulses_HDI.dde`) — always enable this — and, for default PhUI startup, the
    `dde_apps/PHUI2RCP.js` line. Power-cycle; boot takes ~3 minutes, after which the end effector "nods" to
    confirm readiness. To redo calibration later, re-comment both lines so PhUI does not start and block
    DDE access.

*Source: `DDE/InitialCalibration/HDI CAL INSTRUCTIONS- STEP {1,2,3}.pdf`.*

## Boot and PhUI

On power-up, Dexter loads Ubuntu 16.04 from microSD, then — unlike earlier versions — spends a minute or two
**finding its home position via the index eyes**, then (if `RunDexRun` is configured per Step 3.10) enters
**PhUI** and waits for physical commands. **While in any startup mode, including PhUI, the robot does not
respond to DDE or other control software** — only the web interface, SSH, or console work in that window. To
exit PhUI, grip the tool interface and "cog" up (rotate to a detent) without moving sideways until the robot
pushes back and returns home. *Source: wiki `Dexter-Setup.md`, `PhysicalUserInterface.md`.*

## Maintenance

Run the robot through several training series and stress-test for ~36 hours after build. Replace the
strain-wave drive lubricant at **100 hours** and again at **2000 hours**, using the lubricant specified by
the drive vendor ([DC-1](009-Design-Completion.md#strain-wave-component-set)). Adjust belts as needed
(REQ-ENV-4). *Source: factory calibration documentation (Step 3 maintenance note).*

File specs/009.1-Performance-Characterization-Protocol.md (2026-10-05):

# 009.1 — Performance Characterization Protocol

This document specifies how the first physical build is measured: the instruments, the procedure for each
measurement, the rule that decides its result, and where that result is written. It is the instrument
[DC-9](009-Design-Completion.md#performance-characterization) calls for, and carries no design status of
its own — [009](009-Design-Completion.md) owns that.

**No value here is a design value.** Every figure a measurement is compared against is owned by another
document and linked, never restated. Where a requirement is marked *to be characterized* in
[002](002-Requirements.md#3-precision-and-performance-requirements), this protocol produces the value rather
than testing against one: an acceptance threshold invented here would become the answer the build was run
to find.

## Preconditions

The unit these tests run on — what it contains, what it leaves out, and the order it is built in — is
specified in [009.2](009.2-Test-Build-Manifest.md).

| Condition | Source |
|---|---|
| The build is complete through [008.12](008-Assembly.md#00812-firmware-configuration-and-calibration) | [008](008-Assembly.md#assembly-order) |
| The power-on test has passed on this board and harness | [DC-7](009-Design-Completion.md#motor-control-pcb) |
| Factory calibration is complete — required by every check that reads encoder counts | [006 § Step 3](006-Firmware-and-Calibration.md#step-3--movement-calibration-and-go-live) |
| `LinkLengths` carries the specified L4 before any Cartesian move | [006](006-Firmware-and-Calibration.md#firmware-defaults-defaultsmake_ins) |
| The robot has clearance for full rotation on every joint, and no person is within reach while it moves | [006 § Step 2](006-Firmware-and-Calibration.md#step-2--per-joint-eye-calibration) |

⚠️ **J4 has no mechanical end stop.** Its 115-slot track runs the full 360° and no part limits its travel
([DC-11(e)](009-Design-Completion.md#the-j4-code-disk-is-missing)), so the firmware boundaries are the only
limit J4 has. Confirm `J4BoundryHigh`/`J4BoundryLow` are loaded
([006](006-Firmware-and-Calibration.md#firmware-defaults-defaultsmake_ins)) before commanding J4 at all.

**Three measurements are taken during assembly, not after.** The base, the wrist and J3's drive are each open
only once.

| Measurement | Taken at | Specified in |
|---|---|---|
| Mounting face to J2 axis | [008.4](008-Assembly.md#0084-main-pivot) step 17 | [§ 3.1](#test-31-mounting-face-to-j2-axis) |
| Belt centre distance, both stages | [008.9](008-Assembly.md#0089-belts), before ordering belts | [§ 2.2](#test-22-belt-centre-distances) |
| J3 drive closure | [008.8](008-Assembly.md#0088-external-gear), steps 6–13 | [§ 3.3](#test-33-j3-drive-stack) |

**Order.** Section 1 runs on the differential before the covers close. Sections 3.1 and 3.3 run at the
assembly steps the table above gives.
Everything else runs on the calibrated, fully assembled robot, in section order: section 3.2 fixes the
base, section 4 loads it, and section 5 reads a rail while the arm runs.

## Instruments

| Instrument | Resolution required | Used by |
|---|---|---|
| Digital or dial indicator on a magnetic base | 0.001 mm (0.01 mm minimum) | [§ 4.2](#test-42-positioning-repeatability) |
| Digital caliper | 0.01 mm | [§ 1](#section-1-differential-first-build-checklist), [§ 2.2](#test-22-belt-centre-distances) |
| Height gauge or depth caliper, 250 mm range | 0.02 mm | [§ 3.1](#test-31-mounting-face-to-j2-axis), [§ 3.3](#test-33-j3-drive-stack) |
| Steel rule or tape, 1 m | 1 mm | [§ 4.1](#test-41-maximum-reach-and-envelope) |
| Torque wrench, 2–20 N·m | 0.5 N·m | [§ 3.2](#test-32-base-rigidity-under-dynamic-load) |
| Digital multimeter | 10 mV | [§ 5](#section-5-fan-rail-measurement) |
| Bench supply with a current display, or an inline DC ammeter | 10 mA | [§ 4.3](#test-43-rated-payload) |
| Calibrated masses, 0.25 kg steps to 2 kg | 1 % | [§ 4.3](#test-43-rated-payload) |
| Logged command timestamps, or a stopwatch | 0.1 s | [§ 4.4](#test-44-maximum-speed) |

The indicator resolution follows from what is being measured: REQ-PRE-4 predicts a tip resolution of
≈ 3 µm at 0.5 m ([002](002-Requirements.md#3-precision-and-performance-requirements)), and an instrument that
cannot resolve 10 µm cannot measure repeatability on this arm at all. A mark on a board or a photograph of
the tool tip resolves nothing finer than about 1 mm and does not substitute.

---

## Section 1: Differential First-Build Checklist

This section discharges the physical half of the [DC-2](009-Design-Completion.md#differential-detail-design)
contract. Every check is against the differential as [008.6](008-Assembly.md#0086-differential) builds it,
before the covers close.

**A failure here is a print-fit result before it is a design result.** Press interference and bevel
backlash are parameters in
[`diff_params.scad`](../Hardware/Models/700-Differential/diff_params.scad); re-print at an adjusted value
and repeat the check before concluding anything about the design.

### Test 1.1: J4 and J5 travel

Travel limits are [003 § Joint travel limits](003-Kinematics.md#joint-travel-limits). Run the check in two
stages — by hand first, because a mechanism that binds under power has already been driven into the
binding.

1. **By hand, unpowered.** With the differential assembled and before the belts go on
   ([008.9](008-Assembly.md#0089-belts)), turn each of J4 and J5 by hand through its full travel and back.
   Resistance is even across the range. A tight spot, a grinding feel, or a ratcheting step is a fault.

2. **Under power, joint by joint.** Move with the `a` oplet
   ([003 § Motion commands](003-Kinematics.md#motion-commands)), which is coordinated and ramped and needs
   no calibration. Command J4 to 0°, then in 10° steps to ±100°, then to each boundary — **23 positions**.
   Command J5 to 0°, then in 10° steps to ±190° — **39 positions**. Hold 0.5 s at each. At every position
   the joint arrives and holds, nothing stalls, and no grinding is audible.

3. **Both outputs together.** Command the four corners of the travel rectangle and the four edge
   midpoints, holding 1 s at each. The corners are the differential's worst case: the bevel set runs at its
   greatest relative displacement when the two outputs sit at opposite extremes.

**Result:** pass when every commanded position is reached and held, at every stage, with no stall and no
grinding. Encoder agreement at the count level is not tested here —
[§ 4.2](#test-42-positioning-repeatability) measures that on a calibrated robot.

### Test 1.2: Tool conductors through the wrist

The six conductors are fed through Diff Body B at [008.6](008-Assembly.md#0086-differential) step 14, three
per channel, and land on `J20`, `J24` and `J25`
([005 § Tool interface wiring](005-Electronics-and-Control.md#tool-interface-wiring)).

⚠️ **J5 does not rotate continuously.** Its travel is bounded at ±190°
([003](003-Kinematics.md#joint-travel-limits)), so the cycle below is a sweep and return — 380° of travel
per pass — not a revolution.

1. With the bundle dressed as [008.6](008-Assembly.md#0086-differential) leaves it, sweep J5 from one
   boundary to the other and back, **10 passes**.
2. At each boundary, confirm the tool responds — a servo query over the data bus is sufficient
   ([005 § Command interface](005-Electronics-and-Control.md#command-interface)).
3. Inspect the conductors where they leave the shaft at both ends: no abraded or cut insulation, no
   conductor drawn taut, no wrap around a standoff.
4. Pull the bundle at the tool end with ≈ 5 N. It does not move at its strain relief, and no encoder
   reading changes.

**Result:** pass when the insulation is undamaged, the tool answers at both boundaries, and the bundle is
retained. Damage found at one shaft exit only indicates a dressing fault; damage at both indicates the bore
path.

### Test 1.3: Code disks

J4 is read off the 115-slot track cut into `#730-002`'s rim and J5 off `#710-004`, through the Angle and
Rotate shrouds ([004 § Differential interface](004-Mechanical-Architecture.md#differential-interface)).
The instrument is the calibration run itself — this test reads its output for the two wrist joints rather
than repeating a procedure [006](006-Firmware-and-Calibration.md#step-3--movement-calibration-and-go-live)
owns.

1. **From `Check_Eye_Order`:** the J4 and J5 rows each show the clear largest-value pattern.
2. **From `Initial_Scan`:** index-pulse spike separation increases by 2 on each side of the home spikes,
   with no gap inside usable travel, on both wrist joints.
3. **Sweep.** After calibration, move each of J4 and J5 slowly across full travel and back while logging
   the encoder count. The count changes monotonically with commanded direction, no slot is skipped or
   counted twice, and the return reads the start value.

**Result:** pass when both joints calibrate without the opto blocks being revisited and both sweeps are
monotonic. **If J4 fails where J5 passes, suspect the track before the opto block:** J4's slots are cut in
a printed rim rather than a separate disk, so their edges carry that rim's print quality.

**Record:** `J4_track_sweep.csv`, `J5_disk_sweep.csv` — commanded angle and raw encoder count per step.

---

## Section 2: Wrist Station — L4 Measurement

### Test 2.1: L4 from Cartesian residual

**L4 cannot be measured with a caliper.** The J4 and J5 axes **intersect**
([004 § Differential interface](004-Mechanical-Architecture.md#differential-interface)), so there is no
axis-to-axis distance on the built arm to put an instrument across. L4 is the along-arm separation of two
kinematic stations in a five-length model that does not carry the across-arm offset between them
([003 § Link lengths](003-Kinematics.md#link-lengths)), and a quantity of that kind is observable only
through the kinematics it feeds. That is also why the measurement waits for calibration instead of being
taken while the wrist is open.

The observable is Cartesian: an error in L4 displaces every commanded Cartesian position, while `a` and `P`
joint moves are unaffected ([006](006-Firmware-and-Calibration.md#firmware-defaults-defaultsmake_ins)).

1. **Fix a datum.** Mount the indicator from [§ 4.2](#test-42-positioning-repeatability) on a fixed base
   and a target feature at the tool interface.
2. **Pose set.** Choose at least six poses that hold J1, J2 and J3 constant and differ only in J4 and J5,
   spanning each wrist joint's travel. Avoid singular poses
   ([003 § Inverse kinematics](003-Kinematics.md#inverse-kinematics)).
3. **Command and measure.** Command each pose with `M` and measure the actual tip position against the
   datum in all three axes. The set of differences between commanded and measured position is the residual.
4. **Solve.** Repeat the pose set with the `LinkLengths` L4 field set to the specified value and to values
   on either side of it, rewriting the firmware line between runs. The value that minimizes the residual
   is the built arm's L4.

**Result:** the minimizing L4, the residual at that value, and the residual at the specified value. A
residual that stays large at every L4 is the across-arm offset showing itself, which is what
[003 § Link lengths](003-Kinematics.md#link-lengths) records as the cost of the five-length model; report
it as measured rather than adjusting L4 to absorb it.

### Test 2.2: Belt centre distances

Belt lengths are back-solved from the previous version's as-built belts and are confirmed against the built
centre distance before ordering ([007.1 § 3](007.1-Parts-Catalog.md#3-belts-and-pulleys)). Neither path's
centre distance equals its link length, so the figure must come off the build.

For each of the two stages, with the pulleys mounted and before the belt is fitted, measure the distance
between the two pulley axes. Compare against the centre distance
[007.1 § 3](007.1-Parts-Catalog.md#3-belts-and-pulleys) back-solves for that stage.

**Result:** both measured centre distances. These belong to
[DC-3](009-Design-Completion.md#wrist-reduction-ratio); the pulleys they run on are the `config="revised"` parts of
[DC-12](009-Design-Completion.md#wrist-pulley-rework), so take this measurement on those parts.

---

## Section 3: Base First-Build Checklist

This section checks the base, and J3's drive stack. J3 is one of the three base joints
([004](004-Mechanical-Architecture.md#base-joints-j1j3-strain-wave-drive)), and the only one whose drive
closes on a print made for its motor.

### Test 3.1: Mounting face to J2 axis

This test confirms L1 ([003 § Link lengths](003-Kinematics.md#link-lengths)) on the built base. It is
taken at [008.4](008-Assembly.md#0084-main-pivot) step 17 while the stack is open.

1. **Confirm the stack is seated:** the Base Long bears on the Base Mount Bottom's top face with no gap, and
   the Base Motor End Cap's 6810 sits flush with the Base Long's top face
   ([004 § Base mounting plate](004-Mechanical-Architecture.md#base-mounting-plate)).
2. **Measure** from the top face of the Base Mounting Plate — the Base Mount Bottom's mounting face —
   vertically to the J2 axis, with the arm upright. Take the J2 axis at the pivot bore centre, averaging
   readings to both bore edges.

**Pass:** the height is within ±0.5 mm of L1. A reading outside that band means a part is not seated or a
printed height is off; find which. If the stack is seated and the reading still falls outside the band, L1
and the `LinkLengths` line ([006](006-Firmware-and-Calibration.md#firmware-defaults-defaultsmake_ins))
take the measured value.

**Result:** the height in millimetres, and PASS / FAIL.

### Test 3.2: Base rigidity under dynamic load

REQ-ENV-5 requires the mounted plate to react the arm's full dynamic load
([002](002-Requirements.md#7-environmental-and-operational-requirements)). The plate is sized against a
calculated overturning moment that an unbolted plate cannot resist
([004 § Base mounting plate](004-Mechanical-Architecture.md#base-mounting-plate)), so **this test checks
the bolting, not the plate.**

1. **Mount** per [008.2](008-Assembly.md#0082-base) step 5 — through the four corner holes, or the
   equivalent T-slot clamping. The fastener is specified in
   [004 § Base mounting plate](004-Mechanical-Architecture.md#base-mounting-plate).
2. **Torque** each of the four uniformly and record the value. For the specified M6 in class 8.8, 10 N·m
   is ≈ 70 % of proof load at a nominal friction coefficient; reduce it if the work surface cannot carry
   that. Confirm no gap between the plate and the work surface after torquing.
3. **Datum.** Record the distance from a fixed reference on the work surface to one plate corner.
4. **Static case.** Extend the arm horizontally at full reach carrying the largest mass that passed
   [§ 4.3](#test-43-rated-payload), and hold 10 s.
5. **Dynamic case.** Run five cycles of home → full reach → home → opposite full reach → home at the
   configured speed and acceleration ([§ 4.4](#test-44-maximum-speed)).
6. **Re-measure** the corner datum, and re-check the torque on all four fasteners.

**Result:** pass when the corner datum has not moved, no fastener has lost torque, and nothing creaks or
cracks under load. Record the datum before and after, and the torque before and after, for each of the four
positions.

⚠️ Run this test after [§ 4.3](#test-43-rated-payload), not before: it needs the payload that section
measures, and it loads the base harder than anything else in this protocol.

### Test 3.3: J3 drive stack

J3's drive closes between its motor and its Stator Holder on three `config="revised"` prints, and its Flex
Spline Attach is printed for the motor it is fitted to ([008.3](008-Assembly.md#0083-harmonic-drive-motors)).
This test confirms that closure on the built joint. It is taken during
[008.8](008-Assembly.md#0088-external-gear), between step 6 and step 13, while the drive's face is open.

1. **Confirm the prints.** Record the J3 motor's measured body length, the `MOTOR_LEN`
   [`exgear_assembly.scad`](../Hardware/Models/500-ExternalGear/exgear_assembly.scad) was run with, and the
   `hub_drop` J3's Attach was printed at. The first two are the same length, and the drop is the
   `j3_hub_drop` that run echoed.
2. **Upper bearing.** After step 6, before the Stator Holder goes on, turn the External Gear by hand
   through a full revolution. It turns evenly on both 6810s, with no tight spot and no rub.
3. **Closure.** After step 8, measure with a depth caliper how far the wave generator's hub stands beyond
   the circular spline's outer face, at two points 180° apart, and average them. The motor chain carries
   the hub and the Stator Holder carries the spline, so the reading's difference from the protrusion
   [C-201](007.1-Parts-Catalog.md#c-201--521-strain-wave-component-set) gives is how far the two chains
   miss each other, together with any error in the coupler depth set at 008.3 step 10.

**Pass:** the gear turns freely, and the averaged reading is within ±0.3 mm of C-201's protrusion. A
reading outside that band means a part is not seated, the coupler depth is off, or the motor is not the
length the Attach was printed for; find which. If each is right and the reading still falls outside the
band, reprint J3's Attach with its `hub_drop` raised by the amount the reading exceeds C-201's protrusion,
or lowered by the amount it falls short.

**Result:** the three recorded values, the averaged reading, and PASS / FAIL.

---

## Section 4: Performance Envelope

These four measurements produce the values REQ-WS-6, REQ-WS-8 and REQ-PRE-5/6/7 are waiting for
([002](002-Requirements.md#3-precision-and-performance-requirements)). None of them has a pass mark: the
measurement *is* the requirement's value.

### Test 4.1: Maximum reach and envelope

**Datum.** The J1 axis passes through the centre of the robot-side bolt pattern, whose coordinates are
given from that axis ([004 § Base mounting plate](004-Mechanical-Architecture.md#base-mounting-plate));
scribe or otherwise mark that centre on the plate.

1. **Reach.** For each of the eight configuration combinations — the three booleans of
   [003 § Inverse kinematics](003-Kinematics.md#inverse-kinematics) — extend the arm to its furthest
   reachable pose and measure the horizontal distance from the datum to the tool tip.
2. **Envelope.** At a series of heights above the work surface, find the near and far reach boundary in the
   vertical plane and record the pair. The result is a measured side-view profile to set beside the
   profiles [003 § Workspace envelope](003-Kinematics.md#workspace-envelope) refers to.
3. **Physical limits.** At each boundary pose, record whether the limit is the joint boundary, a
   singularity, self-collision, or cable strain. Only the last two are new information from the build; the
   first two the model already predicts.

**Result:** the largest measured reach, the boundary profile, and the limiting cause at each boundary.
These become REQ-WS-6 and REQ-WS-8.

### Test 4.2: Positioning repeatability

Repeatability is the spread of the tip position on repeated returns to one pose. It is **not** accuracy,
and it is not derivable from encoder resolution: the encoder measures the joint, and everything between the
joint and the tip — belt tension, printed-part compliance, bearing clearance — lands in this number and
nowhere else.

1. **Target pose.** A non-singular mid-range pose with the tool interface accessible to an indicator.
2. **Setup.** Magnetic base on the work surface, indicator probing a target feature at the tool interface.
3. **Unidirectional cycle.** Command away from the pose and back, always approaching from the same
   direction, and read the indicator at rest. Repeat **30 cycles**; 10 is the minimum that yields a usable
   standard deviation.
4. **Repeat per axis.** Re-orient the indicator and repeat for each of the three axes.
5. **Bidirectional cycle.** Repeat 10 cycles approaching alternately from opposite directions. The
   difference between the unidirectional and bidirectional spreads is drivetrain backlash reaching the tip.

**Calculation.** Following the ISO 9283 convention for pose repeatability, report the mean distance from
the barycentre of the returned positions plus three standard deviations of that distance. Report the
unidirectional and bidirectional figures separately.

**Result:** repeatability in millimetres per axis, and the combined figure. This becomes REQ-PRE-5. Set
beside REQ-PRE-4's predicted tip resolution, the ratio between the two measures what the structure and
drivetrain cost.

### Test 4.3: Rated payload

⚠️ **Safety.** A stalling joint drops its load. Keep the sweep clear of people, and put a soft surface
under the tool before adding any mass.

⚠️ **The drives bound this test, not the motors, and the stop conditions cannot see it.** Payload is
limited by [C-201](007.1-Parts-Catalog.md#c-201--521-strain-wave-component-set)'s torque ratings long
before anything stalls: this ladder passes the continuous rating at its **second step** and the start/stop
rating before its **sixth** ([003 § Static gravity torque](003-Kinematics.md#static-gravity-torque)). A
strain-wave drive overloaded at the output ratchets or deforms **without** stalling the stepper, drawing
extra supply current, or losing commanded position — so every stop condition below stays quiet while the
damage is done, on three special-order sets that are 9–12 weeks and USD 360 to replace
([DC-1](009-Design-Completion.md#strain-wave-component-set)).

**Bound the ladder at 1.0 kg.** That is a ceiling, not a target: it keeps J2 inside the start/stop rating
with margin and still spans the range the arm is useful over. Holding a static mass briefly above the
continuous rating is what the start/stop rating exists to allow; dwelling there is not. **The arm's own
weight is not what consumes the budget** — Link 2's mass acts behind the J2 axis, so the unloaded worst
case costs a few percent of either limit, and the ladder is measuring payload against the drive almost
directly.

1. Starting at 0 kg, secure a mass at the tool tip and command the arm to a mid-range pose, then to full
   horizontal reach. Hold 10 s at each.
2. At each mass record: whether every joint holds position, whether either move stalled or timed out, and
   the total supply current at rest and during the move.
3. Add 0.25 kg and repeat.

**Stop conditions.** Any one of: **the mass reaches 1.0 kg**; a joint does not hold position under load; a
move stalls or times out; the total supply current reaches the supply's rating
([005 § Power](005-Electronics-and-Control.md#power)). The first is the expected outcome — the others are
faults, and any of them arriving *below* 1.0 kg means something is wrong with the build rather than with
the robot's capacity.

**Result:** the largest mass that cleared every stop condition, and the current-versus-mass series. If the
ladder ends at its 1.0 kg ceiling, REQ-PRE-6 records **"≥ 1.0 kg, drive-limited"** — not a measured
maximum, which this test deliberately does not go looking for.
[§ 3.2](#test-32-base-rigidity-under-dynamic-load) loads the base with the result.
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

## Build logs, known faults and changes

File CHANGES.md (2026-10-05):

# Dexter — Change History

The design history of the Dexter specification, one section per revision, newest first. Each section
records what changed in that revision and why, so the file read top to bottom is the history of the design
and read bottom to top is how the current machine came to be.

- **What a version and a revision are**, how each is branched and tagged, and the procedure for authoring
  the next one: [specs/010-Versioning.md](specs/010-Versioning.md).
- **What is planned but not yet opened as a revision**: [specs/011-Roadmap.md](specs/011-Roadmap.md).
- **What is still open on the current revision**: [specs/009-Design-Completion.md](specs/009-Design-Completion.md).

Each change is a `CR-<version><revision-letter><n>` entry in the format defined in
[010 §5](specs/010-Versioning.md#5-change-record-format). Change IDs are permanent: once published they are
not renumbered or reused, so a superseded change is amended by a later entry rather than edited away.
Statuses carry the meaning defined in [specs/README.md](specs/README.md#design-status) and are recorded as
of the revision's release.

---

## Version 3, revision A — baseline

**Status:** current design of record · **Tag:** `version-3-rev-a`, to be applied when this revision is
released ([010 §3](specs/010-Versioning.md#3-branch-model))

Revision A is the first issue of version 3's design of record and has no predecessor *revision* to delta
against — it establishes the baseline that later revisions delta against. It does have a predecessor
*version*: the changes below are the deliberate departures from version 2, recorded here because they are
the design decisions that define this revision and the reason version 2 is the inherited baseline for
anything version 3 does not independently specify
([010 §1](specs/010-Versioning.md#1-version-lineage)).

### CR-3A1: Belt-reduced wrist (J4/J5)

- **Affects:** [004 §Wrist](specs/004-Mechanical-Architecture.md), [006 §Drive constants](specs/006-Firmware-and-Calibration.md#drive-constants-axiscal)
- **Was:** Version 2 obtained wrist resolution by oscillating the motor across microsteps in firmware
  (`Interpolation` 16× on J4/J5), over a 5.625:1 (16T→90T) belt.
- **Now:** The wrist is resolved through a physical pulley reduction netting **13.5:1**, with
  `Interpolation` = 1 on all joints.
- **Driver:** Wrist resolution and repeatability without firmware microstep oscillation.
- **Status:** `[Specified]` for the net 13.5:1 ratio and the firmware constants;
  `[Provisional]` for the tooth-count realization, which remains open in
  [009](specs/009-Design-Completion.md).
- **Re-derive:** 006 (drive constants), 007 (pulley part numbers), 008 (wrist assembly).
- **Note:** Version 2's driven pulley set is not compatible with the new `AxisCal`; see
  [DC-12](specs/009-Design-Completion.md#wrist-pulley-rework) before reusing wrist pulleys.

### CR-3A2: Bolted base and doubled base clamp

- **Affects:** [004 §Base (J1)](specs/004-Mechanical-Architecture.md#base-j1)
- **Was:** Version 2 stood free on a 6-leg strake base with a single base clamp at the base-to-pivot joint.
- **Now:** The robot mounts to a rigid surface via a bolted metal base plate, and the base-to-pivot joint
  uses a doubled (stacked) base clamp.
- **Driver:** React the arm's full dynamic load through the mounting surface (REQ-ENV-5); stiffen the
  base-to-pivot joint.
- **Status:** `[Provisional]` — base plate design of record established, CAD hole transfer and the double
  clamp detail open in [009](specs/009-Design-Completion.md#base-plate).
- **Re-derive:** 007 (base plate, fasteners), 008 (base assembly and mounting).

### CR-3A3: Factory-recorded calibration

- **Affects:** [006 §Calibration model](specs/006-Firmware-and-Calibration.md#calibration-model)
- **Was:** Version 2 units were calibrated in the field.
- **Now:** Optical-encoder centers and index mapping are calibrated once and recorded onto the
  specific robot; a fielded unit is not re-calibrated. From-scratch builds run the full factory procedure
  once before first use.
- **Driver:** Remove field calibration as a routine operation and make each unit's kinematics traceable to
  a recorded factory measurement.
- **Status:** `[Specified]`.
- **Re-derive:** 008 (bring-up steps reference the recorded calibration rather than a field procedure).

### CR-3A4: Revised link geometry

- **Affects:** [003 §Link lengths](specs/003-Kinematics.md#link-lengths), [004](specs/004-Mechanical-Architecture.md), [007](specs/007-Bill-of-Materials.md)
- **Was:** Link lengths L1–L5 = 228.60 / 320.68 / 330.20 / 50.80 / 82.55 mm. *(This entry originally
  attributed them to version 2; they are **version 1**'s — see
  [CR-3A10](#cr-3a10-l2l3-cut-lengths-corrected-the-comparison-link-set-identified-as-version-1).)*
- **Now:** Link lengths L1–L5 = 235.20 / 339.09 / 307.50 / 59.50 / 82.44 mm (deltas +6.60, +18.42,
  −22.70, +8.70, −0.11 mm). L5 is unchanged within tolerance, consistent with the cross-version tool
  interface.
- **Driver:** Revised arm geometry.
- **Status:** `[Specified]` for the link lengths themselves (source: `Firmware/Defaults.make_ins`). The
  tube cut lengths this entry derived from the deltas above are superseded by
  [CR-3A10](#cr-3a10-l2l3-cut-lengths-corrected-the-comparison-link-set-identified-as-version-1).
- **Re-derive:** 007 (tube cut lengths), 008 (link assembly).

### CR-3A5: Specification restructured as the design of record

- **Affects:** the whole spec set, [specs/README.md](specs/README.md)
- **Was:** Build information was distributed across upstream wiki pages, spreadsheets, video build notes,
  and firmware files, describing what had been observed of the machine.
- **Now:** `specs/` is the authoritative design of record: requirements → kinematics → mechanics →
  electronics/control (002–005), with firmware configuration, bill of materials, and assembly (006–008) as
  derived artifacts. Every item carries a `[Specified]` / `[Provisional]` / `[TBD]` status and a source of
  record, and the decisions still owed on this revision are collected in
  [009](specs/009-Design-Completion.md).
- **Driver:** Make the design buildable from one traceable source, and make the open decisions explicit
  rather than implicit in what the sources did not cover.
- **Status:** `[Specified]`.
- **Re-derive:** n/a — this change defines the derivation order rather than following from it.

### CR-3A6: Parts catalog and printed-parts list added; BOM made orderable

- **Affects:** [007](specs/007-Bill-of-Materials.md), new [007.1](specs/007.1-Parts-Catalog.md) and
  [007.2](specs/007.2-Printed-Parts.md), [009](specs/009-Design-Completion.md),
  [specs/README.md](specs/README.md)
- **Was:** [007](specs/007-Bill-of-Materials.md) listed parts by subassembly with generic descriptions
  ("NEMA-17 stepper", "6810 bearing") and no supplier links. Carbon fiber referenced dead DragonPlate
  `pID=###` identifiers that could not be resolved to any current product. Parts recurring across
  subassemblies had to be summed by hand, and the aggregate table's totals disagreed with the sum of its own
  rows in eight places.
- **Now:** Two derived documents make the design orderable.
  [007.1](specs/007.1-Parts-Catalog.md) is the de-duplicated purchase list for one robot — every bought or
  fabricated item once, with the full specification needed to order correctly and at least one supplier link
  (Canadian first, then US, then elsewhere). [007.2](specs/007.2-Printed-Parts.md) is the de-duplicated
  print list — 109 pieces across 70 distinct parts — with model-file sources. Both carry a regeneration
  procedure. The three carbon fiber cross-sections are resolved to current DragonPlate stock
  (**.125″ × .500″**, **.092″ × .220″**, **.057″ × .177″**), and the metric dimensions in
  [007](specs/007-Bill-of-Materials.md) are recorded as nominal descriptions of imperial pultrusions rather
  than independent specifications. The MicroZed is pinned to `AES-Z7MB-7Z020-SOM-G`, and the AXK0819 thrust
  bearing's conflicting "1/4″" descriptor is corrected to its true 8 mm bore.
- **Driver:** A bill of materials that cannot be ordered from is not a buildable design. Generic part
  descriptions admit wrong parts — "NEMA 17" alone matches over a hundred motors, most of them 1.8°, which
  would silently halve every joint's resolution.
- **Status:** `[Specified]` for the catalog structure and the resolved carbon fiber, MicroZed, and bearing
  identities; `[Provisional]` for five part identities that could not be pinned from the design record,
  collected as [DC-11](specs/009-Design-Completion.md#procurement-data).
- **Re-derive:** 007.1 and 007.2 whenever 007 changes; both documents state the procedure.
- **Note:** Eight aggregate quantities in [007](specs/007-Bill-of-Materials.md) were corrected against the
  sum of its own subassembly rows — most caused by
  [007.3](specs/007-Bill-of-Materials.md#0073-harmonic-drive-motors) being quoted per motor and built twice.
  Anyone who ordered against the previous aggregate table should re-check
  [Corrections to 007](specs/007.1-Parts-Catalog.md#corrections-to-007).

### CR-3A7: Differential detail design authored as parametric OpenSCAD

- **Affects:** [004 §Wrist and differential](specs/004-Mechanical-Architecture.md#wrist-and-differential-j4j5),
  [003 §Link lengths](specs/003-Kinematics.md#link-lengths),
  [007.2 §Differential](specs/007.2-Printed-Parts.md#differential--0076),
  [008.6](specs/008-Assembly.md#0086-differential),
  [009 DC-2/DC-5/DC-6/DC-9/DC-11](specs/009-Design-Completion.md),
  new source in [`Hardware/Models/700-Differential/`](Hardware/Models/700-Differential/)
- **Was:** The differential's internal geometry existed only as the previous version's nine mesh STLs — one
  of them ~1000× oversize, all of them CAD *assembly* exports — with no editable source. DC-2 was the
  largest open item in [009](specs/009-Design-Completion.md); 004 carried the differential detail as
  `[Provisional]`, to be authored rather than recovered; L4 was a 59.50 mm firmware figure the wrist had yet
  to realize; and J4 was credited with a 115-slot code disk.
- **Now:** Every differential part has parametric OpenSCAD source beside its mesh (BOSL2). One `.scad` per
  part, shared dimensions in `diff_params.scad`, the bevel crown in `diff_bevel.scad`, the bought items in
  `diff_hardware.scad`, and `diff_assembly.scad` standing all nine parts and their hardware up as a machine.
  Two parameter sets: `config="previous"` reproduces the built differential; `config="revised"` meets
  [004 §Differential interface](specs/004-Mechanical-Architecture.md#differential-interface) — Diff Body A
  trimmed 80.98 → 77.8 mm for the HDI-940 cover envelope, and the Split Gear's two halves drilled on one
  brad axis. `render-all.rs` renders and checks every part in both configurations; `render-meshes.rs` caches
  the nine as binary STL for the assembly to import, ~54× faster to load than ASCII and carrying more digits
  than the ASCII writer emits. The oversize `710-002` STL is corrected in place (exact 1/1000,
  mate-verified — DC-11(f) closed).
  - **All nine parts are recreations of their references, measured rather than inferred.** Each body is a
    revolve of its **measured meridional profile** (`scadmesh profile`) rather than a stack of inferred
    diameters and face heights, each renders as one closed solid, and each is held to its reference by the
    harness — the two housings included, where an authored functional redesign verified by interface checks
    alone was the earlier plan and is withdrawn. Diff Body A meets the **±0.15 mm** surface gate at
    **0.016 mm** Hausdorff with no sample out of tolerance; Diff Body B is rebuilt from measurement to
    **0.377 mm** candidate→reference and **0.332 mm** reference→candidate, p95 0.136 mm inside tolerance
    both ways, and is not yet gated — what holds it is the chimney base's four unfilleted junctions, which
    are now the worst point in both directions. The
    per-part measurements, the verification contract, and its three exception classes are in
    [DC-2](specs/009-Design-Completion.md#differential-detail-design); the recovered dimensions for each
    part are in the part's own `.scad` header and profile comments, which *are* the dimension tables.
  - **The three bevels are one gear, authored once.** Sections of Split Gear Top and Diff Gear Axle taken
    15.4484 mm apart agree to **0.0001 mm over 4088 points**, already clocked alike, and Split Gear Bottom
    supplies exactly the material inside the 45° parting cone that the Top lacks. The crown is therefore
    defined once in `diff_bevel.scad` — four measured cones and a cubic-Bézier flank, stated about the
    gear's own apex — and each part intersects it with its own envelope, contributing only where that apex
    sits on its axis. Straight bevel teeth are **ruled through the apex**, so one section drawn with
    `linear_extrude(scale=)` is the exact surface and no loft is needed. Diff Gear Shaft's reference carries
    the **previous revision of that gear** (the v1 STEP states one `CONICAL_SURFACE`, slope 1.1834163, in
    all four of its bevels; the shared gear's face cone is 1.14792, in none of them). It is cut to the
    shared crown for a matched set of four, at the cost of the one decided tooth-form exception in DC-2.
  - **The assembly places each part by a feature it already carries**, never by an offset typed a second
    time, so meshing follows from placement: three 20T crowns at 90° mesh when their pitch apexes coincide.
    Checked rather than asserted — the CGAL intersection of the Split Gear against each side bevel is
    **empty**, as it is for whole 20T crowns substituted for both, and the Split Gear's own halves enclose
    **0.000 mm³** between them, meeting face to face on the Ø23 seat floor and the parting cone.
  - **The verification contract is surface-based.** `scadmesh compare` — every reference diameter and face
    position reappearing in the candidate — is a set of one-dimensional histograms, and a solid can satisfy
    all of them and still be the wrong body: it reported 0.006–0.131 mm agreement on parts deviating by up
    to 3.8 mm, and it reported nothing at all on a housing rendering **2.43× the reference's material in an
    identical bounding box**. Parts are gated on two-sided `scadmesh dist`, on `scadmesh segment` for one
    closed solid, and on previewing as well as rendering; `compare` is retained only to name which dimension
    moved once `dist` has failed a part, with each comparison's tolerance set from its own reference's noise
    floor. **A part with no shape contract is not a part that needs less verification; it is a part whose
    verification silently does nothing.**
- **Driver:** DC-2's definition of done — an authored design with source geometry committed, replacing
  mesh-only geometry that could not be edited or checked. An incorrect flex/pivot geometry risks binding the
  joint that also carries the tool wiring through its bore.
- **Status:** `[Specified]` for the authored design and its geometric verification; the physical-build
  checks (binding, wiring survival, code-disk reads) are
  [DC-9](specs/009-Design-Completion.md#performance-characterization)'s first-build checklist.
- **Re-derive:** run `Hardware/Models/700-Differential/render-all.rs` after any `.scad` change and
  `render-meshes.rs` before opening the assembly; regenerate `PART-INDEX.md`/`MANIFEST.csv` after renders
  change committed meshes.
- **Note — five findings the authoring and the assembly produced, the first two of them requirements on
  something outside the differential:**
  1. **L4 as built is 37.53 mm**, not the firmware's 59.50. The wrist axes intersect at the differential
     centre, so L4 is an offset **along the J4 axis** — from where L3 lands on it (Diff Body A's arm
     centreline, z = 11.000) up to the centre (48.5335, fixed by three seats in Body A that agree exactly).
     That sits within 2.0 mm of the CAD frames (39.50) and of HDI-007010's DH `d` term (39.30), while the
     firmware's figure is 22 mm from all three. An earlier split of L4 into a differential contribution plus
     an End Arm Hub standoff is withdrawn: the End Arm Hub is at the **elbow**, a whole L3 from the
     differential, as its own glue rigs show. `diff_assembly.scad` asserts the geometric cluster rather than
     a decomposition; [DC-6](specs/009-Design-Completion.md#link-length-discrepancy-l4) carries the state.
  2. **J4 has no code disk.** Counting slots on every code-disk model gives J1 = 200, J2 = 180, J3 = 157 and
     J5 = 100, each matching [003](specs/003-Kinematics.md#joint-definitions) exactly, and no *disk*
     anywhere carries J4's 115. The track exists: 115 radial slots cut clean through Diff Body B's Ø58.985
     mating rim, on an exact 360/115 pitch, r 24.500–28.800, 0.800 mm wide, read across the pivot from Diff
     Body A. The BOM is not short a row
     ([DC-11(e)](specs/009-Design-Completion.md#the-j4-code-disk-is-missing)).
  3. **The two references put the Split Gear's brad holes 0.5 mm apart** on a Ø1.5 hole, and neither half
     can move to absorb it — the halves are located twice over, by their coincident faces and by the gear.
     `config="revised"` drills both at **z = 12.750**, stated once as `BRAD_Z`: the height both parts have
     material for, and the blind, glued half's own value. Proved by sweeping a Ø1.45 probe along the axis
     and intersecting it with both halves — empty under `revised`, not empty under `previous`.
  4. **Three bought parts have no seat** — the needle thrust stack, the MR85, and the fifth 6703 — found by
     drawing every bought item into the seat it occupies. And the five `#720-005` 60 mm CF strakes listed in
     [007.6](specs/007-Bill-of-Materials.md#0076-differential) are placed by no assembly step and fit no
     slot in the measured geometry. All recorded under
     [DC-11(e)](specs/009-Design-Completion.md#procurement-data).
  5. **The reference meshes are assembly exports and carry features a clean model must not copy** —
     zero-thickness internal shells, and unmerged solids whose file volume double-counts where they
     interpenetrate and whose buried surfaces have no counterpart to measure against. Run `scadmesh segment`
     on a reference before measuring it. One feature read as an artifact is not one: the Diff Gear Shaft's
     twelve Ø0.2 × 60.6 mm through-holes are real voids and the mesh is sound, but at 303:1 they are past
     drilling and far past printing, so they sit behind a `wall_holes` flag.
- **Open:** Diff Body B does not yet meet the ±0.15 mm contract and is absent from `DIST_GATES`. What
  holds it is measured and located: the chimney base's four unfilleted junctions, now the worst point in
  both directions. Two unmodelled R1 edge breaks on the z = 34 clip have been cut along the way, taking
  the candidate side 0.414 → 0.397 → 0.377 mm; neither touches the 0.276 mm interference with the axle
  bevel's toe cone, which is on a different surface and is answered under
  [CR-3A19](#cr-3a19-l1-specified-from-the-base-stack-the-doubled-clamp-withdrawn-6810s-allocated-to-their-seats). Whether the built
  shaft should carry the Ø0.2 wall holes at all is open under DC-11(k).

### CR-3A8: Wrist tooth-count decomposition; design status consolidated into 009

- **Affects:** [004 §Wrist](specs/004-Mechanical-Architecture.md#wrist-and-differential-j4j5),
  [006 §Drive constants](specs/006-Firmware-and-Calibration.md#drive-constants-axiscal),
  [007.1 §3](specs/007.1-Parts-Catalog.md#3-belts-and-pulleys),
  [007.7](specs/007-Bill-of-Materials.md#0077-end-arm-hub),
  [007.2](specs/007.2-Printed-Parts.md#end-arm-hub-and-pulleys--0077);
  [specs/README.md](specs/README.md#document-ownership) and every document in the set.
- **Amends:** [CR-3A1](#cr-3a1-belt-reduced-wrist-j4j5) (closes
  [DC-3](specs/009-Design-Completion.md#wrist-reduction-ratio)).
- **Was:** The 13.5:1 wrist ratio was undecomposed, with no surviving record of the intended tooth split.
  Design status was also duplicated across 201 markers in 002-009, some stale — e.g. 002 still called the
  wrist reduction `[Provisional]` after this same change closed DC-3.
- **Now:**
  - Decomposed to **16T motor → 108T External** (6.75:1) → elbow 1:1 → **40T Internal → 80T differential
    input** (2.0:1) = **13.5:1** net, chosen over 90/96 and 120/72 for margin on both elbow torque and the
    differential's envelope against its cover. Belts: 1176 mm (588T) and 896 mm (448T) × 6 mm GT2 (was
    1120/900 mm) — both superseded by
    [CR-3A10](#cr-3a10-l2l3-cut-lengths-corrected-the-comparison-link-set-identified-as-version-1), which
    re-solves them at unchanged centre distances. Corrects an earlier 004 reading of the differential as
    driven directly off the motor pulley.
  - The HD model set still carries version 2's counts (90T/40T/40T) — five parts need re-cutting, tracked
    as [DC-12](specs/009-Design-Completion.md#wrist-pulley-rework).
  - Design status now owned solely by **009** ([README §Document
    ownership](specs/README.md#document-ownership)): status markers removed from 002-008, 010 and 011;
    004's and 005's status tables became open-item indexes; other stale duplicated prose (L4 splits, BOM
    mismatches, supply substitution limits, the strain-wave component list, stepper requirements, the stale
    `AxisCal.txt` note, version identity, derived-document scopes) corrected to match 009.
- **Driver:** DC-3 required the tooth split be chosen (originator out of business); a value written down
  twice eventually disagrees with itself, with nothing left to say which copy is the design.
- **Re-derive:** 007.1/007.2/007.7 done; 008.5/008.7 pending DC-12's re-cuts. No design value changed by
  the status consolidation.
- **Status:** `[Specified]` for the ratio and tooth counts; belt lengths `[Provisional]` — confirm against
  the measured centre distance before ordering. `[Specified]`/`[Provisional]`/`[TBD]` remain defined in
  [README](specs/README.md#design-status) and are applied in 009 only going forward; prior CR entries keep
  the markers they were written with.

### CR-3A9: Base mounting plate specified; two link datums withdrawn; two model mirrors replaced

- **Affects:** [004 §Base (J1)](specs/004-Mechanical-Architecture.md#base-j1),
  [007.2](specs/007-Bill-of-Materials.md#0072-base),
  [007.1 §C-509](specs/007.1-Parts-Catalog.md#c-509--base-mounting-plate-stock) and
  [§6](specs/007.1-Parts-Catalog.md#6-fasteners),
  [008.2](specs/008-Assembly.md#0082-base), [008.4](specs/008-Assembly.md#0084-main-pivot),
  [009](specs/009-Design-Completion.md); `Hardware/Models/100-Base/`, `Hardware/Models/700-Differential/`.
- **Amends:** [CR-3A2](#cr-3a2-bolted-base-and-doubled-base-clamp) (closes
  [DC-4](specs/009-Design-Completion.md#base-plate)),
  [CR-3A4](#cr-3a4-revised-link-geometry) (DC-5 seat depths, DC-6's L4 reading),
  [CR-3A7](#cr-3a7-differential-detail-design-authored-as-parametric-openscad) (reverts the Diff Body A
  trim recorded there).
- **Was:** The base plate's robot-side pattern was owed as a transfer out of CAD, with bolt size and count
  open and the doubled clamp's stacking "to be confirmed on build"; the doubled clamp was credited with
  L1's +6.6 mm growth over version 2. The adopted L2/L3 cut lengths rested on an unverified assumption
  that socket seat depth was unchanged. L4 was read as 37.53 mm off Diff Body A, and `config="revised"`
  trimmed that body 80.98 → 77.8 mm to clear the HDI-940 cover. Two mirror files held the wrong part.
- **Now:**
  - **Base plate specified and drawn.** The robot-side pattern is **8 × Ø6.000 mm** through the mount's
    150 × 150 × 10 mm flange, in pairs on its four edges at (±12.500, ±62.500) and (±62.500, ±12.500) —
    not a bolt circle, and unchanged by a 90° rotation of the robot on its plate. Each opens into a
    Ø10.000 counterbore driven from inside the base. The bolt is **M6 × 18 mm, 8 off**; as printed the
    flange is under size for it on both diameters, so the eight holes are opened on assembly to **Ø6.6
    through with a Ø11.0 counterbore**. The work-surface side is **4 × Ø6.6 mm at (±85.000, ±85.000)**,
    taking M6 bolt, washer, and nut with length set by the work surface, or a T-slot clamp on the same
    four corners; the Base Clamps carry no part of this load path. The plate is
    **`#110-004`**, authored as parametric OpenSCAD (the first part outside the differential to have
    source), emitting its own machining DXF; `check.rs` asserts its eight tapped centres against the
    mount's mesh rather than against this document, and fails on a 0.1 mm move.
  - **Doubled clamp resolved from geometry, not deferred to a build.** The clamps stack face to face on
    the mount's 97.000 mm shoulder, and because the Base Long bottoms on nothing the second clamp raises
    J2 by its full **15.000 mm**. The +6.6 mm attribution is therefore **withdrawn**: 15.000 mm is
    neither that, nor the 4.000 mm by which the CAD model falls short of firmware L1. That disagreement
    is raised as [DC-13](specs/009-Design-Completion.md#base-height-and-l1) and belongs to L1.
  - **L2/L3 seat depths validated.** Seat depth is unchanged across versions (L3 exactly, L2 by 0.011 mm).
    L3 is a **spigot, not a socket** — the hub plugs into the tube — and the 0.75″ tube's OD is **22.0 mm,
    wall ≈.038″**, not the .050″ previously assumed. The cut lengths this entry read off those seats
    (282.4 / 214.3 mm) are superseded by
    [CR-3A10](#cr-3a10-l2l3-cut-lengths-corrected-the-comparison-link-set-identified-as-version-1).
  - **L4 = 37.53 mm withdrawn.** Diff Body A's 81 mm arm is the **tool** arm, perpendicular to the L3 tube
    and in the other half of the wrist, so it cannot be where L3 lands. L4 now rests on two geometric
    readings that agree (glTF 39.5 mm, measured DH 39.3 mm) and disagree with firmware's 59.50 mm.
    **`BODY_A_LEN` reverts to 81.0 mm** in both configurations, since the envelope conflict that motivated
    the trim does not exist; `COVER_ENVELOPE` is dropped with the asserts that read it.
  - **Two model mirrors replaced.** `#200-001` Arm Body held `ArmBodyFrontStrakeMED.stl` byte for byte
    (name-prefix match), and `#110-001` Base Mount Bottom held version 2's un-bolted 6-leg strake base —
    150 × 150 × 98 mm bolted part now installed, which is what made DC-4's pattern recoverable at all.
    Both were well-formed, correctly named meshes of the wrong part, which is precisely what
    `MANIFEST.csv` cannot detect.
- **Driver:** Close DC-4 and DC-5's checks against measurement rather than assumption; stop a reading
  that two parts cannot share from propagating into L4 and into the differential's geometry.
- **Re-derive:** 007.1/007.2 done (plate stock, M6 line, M3 nut and clamp-screw counts recomputed to 45
  and 2); 008.2/008.4 unblocked; 003's L1 pending DC-13's measurement, which is queued with
  [DC-9](specs/009-Design-Completion.md#performance-characterization)'s base load check because the base
  is only apart once.
- **Status:** `[Specified]` for the base plate, its pattern, its hardware, and the clamp stack (DC-4
  closed). `[Provisional]` for L2/L3 as recorded here, superseded by
  [CR-3A10](#cr-3a10-l2l3-cut-lengths-corrected-the-comparison-link-set-identified-as-version-1). `[TBD]` for
  [L4](specs/009-Design-Completion.md#link-length-discrepancy-l4) and
  [L1](specs/009-Design-Completion.md#base-height-and-l1); the firmware file stands as the record for both
  until a unit is measured.

### CR-3A10: L2/L3 cut lengths corrected; the comparison link set identified as version 1

- **Affects:** [003 §Link lengths](specs/003-Kinematics.md#link-lengths),
  [007 §007.1](specs/007-Bill-of-Materials.md#0071-glue-rig-assembly),
  [007.5](specs/007-Bill-of-Materials.md#0075-arm-body),
  [007.7](specs/007-Bill-of-Materials.md#0077-end-arm-hub),
  [007.1 §3](specs/007.1-Parts-Catalog.md#3-belts-and-pulleys) and
  [§5](specs/007.1-Parts-Catalog.md#5-structural-composites-and-metal-stock),
  [007.2 §Tooling](specs/007.2-Printed-Parts.md#tooling--glue-rigs),
  [009](specs/009-Design-Completion.md); `Hardware/Models/PART-INDEX.md`.
- **Amends:** [CR-3A4](#cr-3a4-revised-link-geometry) (the comparison link set and the derived cut
  lengths), [CR-3A8](#cr-3a8-wrist-tooth-count-decomposition-design-status-consolidated-into-009) (both
  belt lengths), [CR-3A9](#cr-3a9-base-mounting-plate-specified-two-link-datums-withdrawn-two-model-mirrors-replaced)
  (the L2/L3 status recorded there).
- **Was:** The link-length comparison column in 003 was labelled "previous version", and the L2/L3 tube
  cut lengths were derived from it as `tube_previous + link_delta`, giving 282.4 mm and 214.3 mm. The two
  wrist belts were re-solved at centre distances carrying the same deltas. The glue rigs were recorded as
  tooling that consumes extra copies of the robot's own parts, and the eight jig bodies in `950-Tooling/`
  as possible orphans of a superseded rig design.
- **Now:**
  - **The comparison set is version 1, not version 2.** `dde/core/robot.js` carries both link sets on one
    line per link and labels them `HDI` and `ORIG DEX`. [010](specs/010-Versioning.md#1-version-lineage)
    records no link change between versions 2 and 3, so there is **no version 2 → 3 delta to apply to a
    version 2 part**, and the deltas in 003's table span two version steps.
  - **L2 = 264.0 mm and L3 = 243.0 mm** — the previous version's tubes, carried across unchanged. Both are
    re-derived against the current kinematics rather than by delta: L2 closes stop to stop at
    37.513 + 264.000 + 37.500 = **339.013 mm** against the firmware's 339.092, and L3's far face sits
    28.500 + 243.000 = 271.500 mm from J3, putting its stop 36.000 mm short of a J4 axis that both the
    firmware and the CAD model place at 307.500 mm. The superseded figures would have left L2 18.4 mm long
    and L3 22.7 mm short.
  - **L2's far end is `#410-001` Axis Intersection Half**, whose Ø42.000 mm J3 bore and blind 29.000 mm
    channel end at −37.500 mm are measured on the part. It was previously believed to be
    `HDI-330-002_ArmBodyHubB`, a clamp half with no file; that part is the clamp at the same joint, with
    its node origin on the J3 axis.
  - **Belts re-solved at unchanged centre distances: 1140 mm (570T) and 940 mm (470T)** × 6 mm GT2,
    replacing 1176 mm and 896 mm. Only the tooth counts move the length.
  - **The glue rigs resolved as tooling.** Each of the eight jig bodies is a trough holding both ends of
    one bonded span at its finished spacing, with the negative of the part it seats at each end — which is
    how L2's far end was identified. They consume **no** extra copies of robot parts; 007's 007.1
    subassembly, 007.1 §8 and 007.2's tooling total are corrected accordingly, and
    [C-404](specs/007.1-Parts-Catalog.md#4-bearings)'s *(+2 tooling)* 6703s drop — the catalog quantity is
    **10**, unchanged.
- **Driver:** A cut length is unrecoverable if it is short, and the derivation that set both rested on a
  column whose provenance had never been traced to a source file.
- **Re-derive:** 007/007.1/007.2 done (cut lengths, belt lengths, CF stock figures, tooling totals);
  008's belt-fitting step updated to the new lengths.
- **Status:** `[Specified]` for both cut lengths and for the glue rigs
  ([DC-5](specs/009-Design-Completion.md#link-member-lengths) closed). `[Provisional]` for the two belt
  lengths, which still stand on a routing no file places
  ([DC-3](specs/009-Design-Completion.md#wrist-reduction-ratio)). The part at L3's far end remains absent
  from the model set ([DC-11(h)](specs/009-Design-Completion.md#procurement-data)); no cut length depends
  on it.

### CR-3A11: Work-surface fastener specified

- **Affects:** [004 §Base mounting plate](specs/004-Mechanical-Architecture.md#base-mounting-plate),
  [007 §007.2](specs/007-Bill-of-Materials.md#0072-base),
  [007.1 §6](specs/007.1-Parts-Catalog.md#6-fasteners),
  [008 §008.2](specs/008-Assembly.md#0082-base).
- **Amends:** [CR-3A9](#cr-3a9-base-mounting-plate-specified-two-link-datums-withdrawn-two-model-mirrors-replaced)
  (the plate-to-bench fastener).
- **Was:** "M6 bolt, washer, and nut, 4 sets", with length "to suit the work surface" and no property
  class — not orderable as written.
- **Now:** **M6, property class 8.8 or better, one plain washer under the head and one under the nut,
  4 sets.** Length is **9.5 mm plate + work-surface thickness + 12 mm**, rounded up to a stock length. The
  work surface must give access to its underside for the nuts; where it does not, the T-slot clamp
  alternative already recorded in 004 applies.
- **Driver:** The four corner fasteners are the plate's only tie to the bench and carry ≈300 N at the far
  bolt; the entry did not state a class, a length rule, or what to do on a bench with no underside access.
- **Re-derive:** 007/007.1 fastener rows done.
- **Status:** `[Specified]`.

### CR-3A12: L4 specified along the arm; the DH `d` corroboration withdrawn

- **Affects:** [003 §Link lengths](specs/003-Kinematics.md#link-lengths),
  [§DH model](specs/003-Kinematics.md#denavithartenberg-model) and
  [§Workspace envelope](specs/003-Kinematics.md#workspace-envelope),
  [002 §2](specs/002-Requirements.md#2-kinematic-and-workspace-requirements),
  [004 §Differential interface](specs/004-Mechanical-Architecture.md#differential-interface),
  [006 §Firmware defaults](specs/006-Firmware-and-Calibration.md#firmware-defaults-defaultsmake_ins),
  [009](specs/009-Design-Completion.md).
- **Amends:** [CR-3A4](#cr-3a4-revised-link-geometry) (L4's value),
  [CR-3A8](#cr-3a8-wrist-tooth-count-decomposition-design-status-consolidated-into-009) (note 1's
  corroboration of the 37.53 mm reading),
  [CR-3A9](#cr-3a9-base-mounting-plate-specified-two-link-datums-withdrawn-two-model-mirrors-replaced)
  (L4's `[TBD]` status, the two readings recorded there as agreeing, and the firmware file standing as its
  record).
- **Was:** L4 = 59.50 mm on the authority of `Firmware/Defaults.make_ins`, with three competing readings
  open against it — the wiki's 50.95 mm, the CAD kinematic frames' 39.50 mm, and HDI-007010's DH `d` term
  at 39.30 mm — the last two held to be independent geometric readings agreeing to within 0.2 mm. Closing
  the item was owed a caliper measurement on a first build, and a datum that the model set could not reach.
- **Now:**
  - **L4 = 39.50 mm, and link lengths are along-arm components.** The `DexterHDI_Link*_KinematicAssembly`
    origins in `dde/HDIMeterModel.gltf` place each joint station on the arm axis with an offset across it.
    Taking the along-arm component alone reproduces the firmware's L3 to the micron (307.5000 against
    307.500) and its L2 to 3 µm (339.0945 against 339.092). Under that convention the J4 → J5 span reads
    **39.500 mm along the arm, −20.000 mm across it**, so L4 = 39.50 mm.
  - **The firmware's 59.50 mm is the two components added together** — 39.500 + 20.000 — and is neither
    the along-arm component nor the 44.275 mm distance between the two stations. `Defaults.make_ins` needs
    `39500` in that field; every other field stands.
  - **The DH `d` corroboration is withdrawn.** J2, J3 and J4 are parallel pitch axes (α = 180.43° and
    0.81° on the J2 and J3 rows), and between parallel axes the common normal has no determined position,
    so `d` on the rows that follow them is a fit parameter, not a measured offset. The J4 row's
    `d` = 39.300 mm is not a reading of L4 and its closeness to 39.50 mm is coincidence; that row's
    `a` = −0.000049 m is what it does say, which is that the wrist axes intersect. The DH set's **`a`**
    terms remain the cross-check on L2, L3 and L5.
  - **The wiki's pair is version 1's set** — L5 identical to 0.001 mm, L4 within 0.15 mm of version 1's
    2.000 in — not an alternate reading of this version, so it competes with nothing.
  - **The open datum is settled.** Where L3 lands on the J4 axis is the J4 station, which the same chain
    places 307.500 mm along the arm from J3. It never depended on the bracket that carries the
    differential off the L3 tube, which remains absent from the model set
    ([DC-11(h)](specs/009-Design-Completion.md#procurement-data)).
- **Driver:** The item could not be closed while its two supporting readings were believed to measure the
  same quantity, and the firmware field it disagrees with silently displaces every commanded Cartesian
  position by the error.
- **Re-derive:** 004's differential-interface prose done (the frame separation now reads as L4; the
  withdrawn 37.53 mm decomposition and its narrative are gone); 006's `LinkLengths` block carries `39500`
  with the deviation from the shipped file called out; the derived maximum reach falls 20.00 mm to
  **≈ 0.77 m** in 003 § Workspace envelope and REQ-WS-6; 009's DC-6 closed and its measurement moved to
  [DC-9](specs/009-Design-Completion.md#performance-characterization). No cut length, belt length, or
  printed part derives from L4.
- **Status:** `[Specified]` for L4 and for the along-arm convention
  ([DC-6](specs/009-Design-Completion.md#link-length-discrepancy-l4) closed). The built J4 → J5 station
  separation is measured with DC-9's first-build checks; L1 remains `[TBD]` under
  [DC-13](specs/009-Design-Completion.md#base-height-and-l1), where the same convention makes the 4.000 mm
  a disagreement over the base stack.

### CR-3A13: Motor Control PCB connector map recovered from the schematic

- **Affects:** [005 §Boards](specs/005-Electronics-and-Control.md#boards),
  [005 §Power](specs/005-Electronics-and-Control.md#power),
  [005 §Tool interface wiring](specs/005-Electronics-and-Control.md#tool-interface-wiring),
  [007.1 §7](specs/007.1-Parts-Catalog.md#7-electronics-and-wiring),
  [008 §008.10](specs/008-Assembly.md#00810-wire-harness),
  [009](specs/009-Design-Completion.md).
- **Was:** The board's connectors were given as four groups — `J1`–`J6`/`J24` motor screw terminals,
  `J7`–`J13` opto headers, `J14`–`J17` tool headers, `J19`–`J21` power — with no map from a connector to
  the joint it serves, and a tool conductor's landing named only for White, as "the 2nd-from-top '−' screw
  terminal". The logic rails were said to derive from the motor rail, and `D3`/`D4` to be the input
  rectification.
- **Now:** Every connector on the board is mapped in [005 §Boards](specs/005-Electronics-and-Control.md#boards)
  from the schematic (`Hardware/09011-00135-A.PDF`), and each of the six tool conductors carries its board
  landing in [005 §Tool interface wiring](specs/005-Electronics-and-Control.md#tool-interface-wiring).
  Four of the earlier groupings were wrong: `J24` is the main power input (`VIN1`/`GND1`/`VIN2`/`GND2`),
  not a seventh motor terminal; `J9` is the MicroZed `JX2` carrier connector, not an opto header;
  `J14`–`J17` are the differential analog inputs `ANA_1`–`ANA_4`, not tool headers; and `J19`–`J21` are the
  debug port and the two FPGA `AUX` pairs, not power. **The board's channel order is the firmware's axis
  order — Base, End, Pivot, Angle, Rotate — so the Pivot and End channels cross over relative to joint
  number**, and the opto headers run in a third order again. `U1`/`U2` buck the logic rails from the input
  rail ahead of the boost; `D3`/`D4` are those bucks' catch diodes, which is what the "D3/D4 fix" naming
  this board revision corrects, and `D6` is the input series Schottky.
- **Driver:** [DC-7](specs/009-Design-Completion.md#motor-control-pcb) closes on a physical power-on test,
  and the specification did not say where a single wire goes. Wiring by connector number rather than by
  joint name drives two joints from each other's channels, and the White conductor's landing — the one
  cross-version hazard on this board — could not be checked before power without the schematic.
- **Re-derive:** [008.10](specs/008-Assembly.md#00810-wire-harness) gains the opto-jumper, motor, and opto
  landing steps it did not have; DC-7's definition of done is now the power-on procedure itself;
  [DC-11(b)](specs/009-Design-Completion.md#procurement-data) and
  [C-716](specs/007.1-Parts-Catalog.md#7-electronics-and-wiring) narrow to fan size and part number, the
  board side being settled, with the rail at `J23` read during DC-7's test.
- **Status:** `[Specified]` for the connector map, the harness landings, and the rail derivation.
  [DC-7](specs/009-Design-Completion.md#motor-control-pcb) stays `[Provisional]`: nothing here substitutes
  for running a unit on the board.

### CR-3A14: Power supply, its inlet connector, and the supply wiring specified

- **Affects:** [002 §REQ-CTL-5](specs/002-Requirements.md),
  [005 §Power](specs/005-Electronics-and-Control.md#power),
  [007 §007.10](specs/007-Bill-of-Materials.md#00710-wire-harness),
  [007.1 §C-103](specs/007.1-Parts-Catalog.md#c-103--power-supply-36-v-dc) and §7 (C-714, C-715, C-718),
  [008 §008.10](specs/008-Assembly.md#00810-wire-harness),
  [009 §DC-11](specs/009-Design-Completion.md#procurement-data) and
  [§DC-14](specs/009-Design-Completion.md#power-inlet-mounting),
  [011 item 3](specs/011-Roadmap.md).
- **Was:** The rating read **36 V / 4 A** as a fixed figure in the requirement, in 005, and in the bill of
  materials, while the catalog read **≥ 4 A** and recommended a 4.44 A part — so the recommended supply did
  not meet the rating as the other three documents stated it. C-103 specified the supply as carrying "a DC
  barrel plug" and sent the builder to [C-712](specs/007.1-Parts-Catalog.md#7-electronics-and-wiring) for
  the mating part and to C-711/C-712 to fit the connector; those are the tool 3-pin connector and square
  pin header stock. No supply model was named, [C-715](specs/007.1-Parts-Catalog.md#7-electronics-and-wiring)
  was "match to the PSU plug you order" and unorderable, [008.10](specs/008-Assembly.md#00810-wire-harness)
  step 9 landed power wires on `J24` without ever terminating their other end, and no mains cord appeared
  in any list. [DC-8](specs/009-Design-Completion.md#power-supply) was closed and the connector was booked
  nowhere.
- **Now:** The rating is **36 V DC, ≥ 4 A (≈144 W)** in all four documents, the current being a floor the
  supply must meet rather than a figure it must equal. The supply of record is **MEAN WELL
  `GST160A36-R7B`**, whose `-R7B` order suffix *is* its plug code: a **KYCON `KPPX-4P` equivalent 4-pin
  DIN**, pins 1/4 `+Vo` and 2/3 `−Vo`. **The barrel-plug premise is withdrawn** — C-103 had asserted a
  connector its own candidate does not have. The inlet is that plug's snap-and-lock mate, KYCON
  **`KPJX-PM-4S`** (48 V DC, 7.5 A per pin), and 008.10 step 9 now lands both pins of each polarity and
  mounts the receptacle before wiring `J24`. Two dependent corrections follow: the inlet wire goes to
  **18 AWG**, C-715's datasheet specifying #18 for its power pins where the inherited 24 AWG is undersized
  for a 4 A rail; and an **IEC C13 line cord** ([C-718](specs/007.1-Parts-Catalog.md#7-electronics-and-wiring))
  joins the bill, the adapter having a C14 inlet and shipping without one. 005 records that under-voltage
  does not damage the board — it degrades motion — so only the 38 V ceiling is a damage limit, and carries
  the converse hazard the source warns of: this supply into a laptop expecting 12 V or 24 V can destroy
  the laptop.
- **Driver:** A builder pricing the supply could not tell whether a 4.44 A brick was over-rated or out of
  spec, and following C-103's connector references ordered the wrong two parts — for a plug the supply
  does not carry. Retention drove the connector choice over a barrel jack: the arm moves under power.
- **Re-derive:** [007.10](specs/007-Bill-of-Materials.md#00710-wire-harness) gains a mains-cord row and
  carries the new gauge on `#840-001`; [008.10](specs/008-Assembly.md#00810-wire-harness) step 9 is
  rewritten; [DC-11(j)](specs/009-Design-Completion.md#procurement-data) closes, and closing it opens
  [DC-14](specs/009-Design-Completion.md#power-inlet-mounting) — the receptacle is panel-mount and nothing
  in the build list carries a panel.
- **Status:** `[Specified]`. [DC-8](specs/009-Design-Completion.md#power-supply) never covered the
  connector — it closed on the rating, and stays closed on it.
- **Note:** USB-C PD 3.1 EPR supplies 36 V natively and was evaluated as the inlet. It does not fit this
  board — EPR's expected maximum at 36 V nominal is 38.3 V against the `LTC3786`'s 38 V, an unclamped
  disconnect transient reaches 44.3 V, and EPR drops the rail after one second of silence from the sink.
  It is recorded against the purpose-built board in [011 item 3](specs/011-Roadmap.md) instead.

### CR-3A15: DC-9 made executable — the measurement protocol, the build that runs it, and the motion shaping parameters it commands

- **Affects:** [009.1](specs/009.1-Performance-Characterization-Protocol.md) (new),
  [009.2](specs/009.2-Test-Build-Manifest.md) (new),
  [006 §Motion shaping parameters](specs/006-Firmware-and-Calibration.md#motion-shaping-parameters),
  [009 §DC-9](specs/009-Design-Completion.md#performance-characterization),
  [009 §DC-11](specs/009-Design-Completion.md#procurement-data),
  [README](specs/README.md#document-ownership).
- **Was:** [DC-9](specs/009-Design-Completion.md#performance-characterization) named four measurements and
  three inherited checklists but specified no procedure for any of them, and nothing anywhere said what
  build to run them on. 007 lists parts by subassembly and 008 gives an assembly order, but neither says
  which subset a characterization build needs, what can be deferred, or what must be settled before
  ordering. So the one item that can only be closed on a physical build had nothing a builder could
  execute and no build to execute it against. `MaxSpeed` and `Acceleration` were referred to by name in
  002 and 003 and defined nowhere; neither is in `Defaults.make_ins`.
- **Now:** [009.1](specs/009.1-Performance-Characterization-Protocol.md) specifies each measurement: the
  instrument and the resolution it must reach, the procedure, the rule that decides the result, and — in
  its [§ 7](specs/009.1-Performance-Characterization-Protocol.md#section-7-closing-out) — the document each
  result is written into. Where 002 marks a requirement for characterization, no acceptance threshold is
  stated: the measurement is the value, and a threshold invented in advance would become the answer the
  build was run to find. [009.2](specs/009.2-Test-Build-Manifest.md) specifies the build that protocol runs
  on, as seven stages, each drawing named 007 subassemblies, assembled by named 008 procedures, and each
  closing specific open items before the next is committed; it carries a table mapping every open item in
  009 to the stage that answers it. 006 now specifies the motion shaping parameters, including that the
  `S, MaxSpeed` argument is scaled by `arcsec_per_nbits` = 0.46423 rather than taken as arcsec/s — a value
  read as arcsec/s overstates the commanded speed by ≈ 2.15×.
- **Driver:** Four requirements (REQ-PRE-5/6/7, REQ-WS-6/8) and three design-completion items wait on
  measurements that no document described how to take. Sequencing the build is worth specifying for its
  own reasons: ordering the strain-wave sets last would add months, and belts or a fan bought before the
  measurements that size them would be bought twice.
- **Status:** `[TBD]` for DC-9 itself, which still requires a build. The protocol that closes it, and the
  build it is run on, are specified; the build does not exist.
- **Re-derive:** Nothing downstream. 009.1 produces values and consumes none that are not linked to their
  owner; 009.2 selects from 007 and 008 and states no quantity of its own.
- **Open:** Three items are **gates, not outputs** — the build cannot be completed without them.
  [DC-10](specs/009-Design-Completion.md#from-scratch-calibration-files)'s two job wrappers are what
  [006 §Steps 2–3](specs/006-Firmware-and-Calibration.md#factory-calibration-procedure) run, so without
  them there is no calibration and most of 009.1 cannot be executed at all.
  [DC-12](specs/009-Design-Completion.md#wrist-pulley-rework) must be closed before the wrist parts are
  printed, or every commanded J4 and J5 angle is scaled by 2.4 against the specified `AxisCal`.
  [DC-11(h)](specs/009-Design-Completion.md#procurement-data) is the hard one: no part in the set bridges
  the elbow tube to the wrist, so there is no complete arm to characterize until one is designed.
  [DC-14](specs/009-Design-Completion.md#power-inlet-mounting) alone is deferrable — the test build takes
  bench leads to `J24` and does not close it.
- **Note:** Four corrections were forced while authoring the protocol, each a procedure that could not have
  been run as written. **J4 cannot be rotated 360°** — it is bounded at ±108.3°, and the checklist item
  that commanded a full turn to count its 115-slot track is not executable; the track is read across its
  bounded travel. **J5 does not rotate continuously** — its cycle is a 380° sweep and return, not a
  revolution. **L4 cannot be measured dimensionally**: the J4 and J5 axes intersect
  ([004 §Differential interface](specs/004-Mechanical-Architecture.md#differential-interface)), so no
  instrument can be put across them and the check is kinematic, on a calibrated robot, rather than taken
  while the wrist is open as DC-9 previously directed. **`J23` is the fan connector**, not the motor rail
  — [DC-7](specs/009-Design-Completion.md#motor-control-pcb) criterion 3 reads it precisely because the
  rail feeding it is unknown, so the protocol states no expected voltage.

### CR-3A16: Calibration job files restored from repository history; J4 slot count corrected in both

- **Affects:** `DDE/InitialCalibration/Setup_Find_Index_Home_HDIv2.dde` (restored),
  `Firmware/dde_apps/Find_Index_Pulses_HDI.dde` (restored),
  [006 §Calibration model](specs/006-Firmware-and-Calibration.md#calibration-model),
  [006 §Factory calibration procedure](specs/006-Firmware-and-Calibration.md#factory-calibration-procedure),
  [006 §Encoder velocity monitor](specs/006-Firmware-and-Calibration.md#encoder-velocity-monitor) (new),
  [009 §DC-10](specs/009-Design-Completion.md#from-scratch-calibration-files),
  [009.2 §Gate items](specs/009.2-Test-Build-Manifest.md#gate-items--close-these-before-cutting-anything)
  and §Stage 6.
- **Was:** [DC-10](specs/009-Design-Completion.md#from-scratch-calibration-files) held that the two job
  files driving [006 Steps 2–3](specs/006-Firmware-and-Calibration.md#factory-calibration-procedure) were
  missing from the public repository, that they were thin wrappers over the calibration engine in
  `dde/low_level_dexter/`, and that reconstructing them against that engine was the only route. It was a
  gate on the whole test build, and 006 named the Step 2 file only by a glob.
- **Now:** Both files are in the repository. They were committed with the design and deleted from it in
  October 2020 — `Find_Index_Pulses_HDI.dde` at `e4a3a0d` (2020-10-27),
  `Setup_Find_Index_Home_HDIv2.dde` at `1b121ce` (2020-10-29) — in a run of six pure deletions that added
  nothing in their place, and they are restored from that history. Neither is a wrapper: the index-eye
  search, the scan thresholds, and the home-offset arithmetic are in the job files, and every routine
  [006 Step 3](specs/006-Firmware-and-Calibration.md#factory-calibration-procedure) names is a job defined
  in the Step 2 file — none of them exists anywhere else in either repository. `Find_Index_Pulses_HDI.dde`
  is restored at its **2020-10-16** content, which reads the joint boundaries from `Defaults.make_ins`
  rather than setting a narrower set inside the job, so the job agrees with
  [003 §Joint travel limits](specs/003-Kinematics.md#joint-travel-limits). 006 now names both files by
  path, and 009.2 drops DC-10 as a gate: nothing is owed before cutting, and the item closes when the
  files run.
- **Driver:** DC-10 gated every measurement in [009.1](specs/009.1-Performance-Characterization-Protocol.md)
  that needs trustworthy encoder counts, and it was scoped as reconstruction of two wrappers — work that
  would in fact have meant re-authoring the entire index-eye algorithm, against an engine that does not
  contain it.
- **Status:** `[Provisional]` — DC-10 stays open on the one thing left: running
  [006 Steps 2 and 3](specs/006-Firmware-and-Calibration.md#factory-calibration-procedure) end to end on a
  build. The files have not been run since they were restored.
- **Re-derive:** Nothing downstream. 006 gains file paths it referred to by glob; 009.2's gate table and
  stage 6 follow DC-10's change of kind.
- **Note:** **One correction is applied to both files.** Each declared
  `n_eyes = [200, 180, 157, 113, 100]`, the per-joint slot counts the eye-to-angle conversion
  `deg_per_eye = 360 / n_eyes` is built from; J4's term is **115**
  ([003 §Joint definitions](specs/003-Kinematics.md#joint-definitions), counted on `#730-002`'s rim, and
  carried by `DexRun.c`), so at 113 every J4 eye hop ran 1.8 % long. Recovered SHA-256 `e07b3602…e4e0b0`
  and `8fed1af9…e9d6ff`; corrected `b0d9322c…8b88c02` and `34cededd…4b3ec1`. **A second slot-count
  disagreement is left alone and specified instead.** `DexRun.c`'s `monitorTorque` reads J2 as 184 slots
  against the disk's 180, but its `joints_slots` and `joints_corr` arrays are an empirically fitted pair
  and correcting one term alone de-tunes the other — see
  [006 §Encoder velocity monitor](specs/006-Firmware-and-Calibration.md#encoder-velocity-monitor). Two
  superseded Step 2 variants, `Setup_Find_Index_Home_HDI.dde` and `Setup_Find_Index_Home_HDI_Stable.dde`,
  remain in history and are not restored; `HDI CAL INSTRUCTIONS- STEP 2.pdf` names `HDIv2`.

### CR-3A17: DC-11 resolved to a coupon print

- **Affects:** [003 §Static gravity torque](specs/003-Kinematics.md#static-gravity-torque),
  [003 §Link lengths](specs/003-Kinematics.md#link-lengths),
  [004 §Differential interface](specs/004-Mechanical-Architecture.md#differential-interface),
  [005 §Open items](specs/005-Electronics-and-Control.md#open-items),
  [007 §7.5](specs/007-Bill-of-Materials.md#0075-arm-body),
  [007 §7.6](specs/007-Bill-of-Materials.md#0076-differential),
  [007 §Aggregate](specs/007-Bill-of-Materials.md#aggregate-hardware-quantities-whole-robot),
  [007.1 §4](specs/007.1-Parts-Catalog.md#4-bearings),
  [007.1 §5](specs/007.1-Parts-Catalog.md#5-structural-composites-and-metal-stock),
  [007.1 §7](specs/007.1-Parts-Catalog.md#7-electronics-and-wiring),
  [007.1 §C-101](specs/007.1-Parts-Catalog.md#c-101--nema-17-stepper-09step),
  [007.1 §C-201](specs/007.1-Parts-Catalog.md#c-201--521-strain-wave-component-set),
  [007.1 §C-503](specs/007.1-Parts-Catalog.md#c-503--carbon-fibre-strip-057--177),
  [007.1 §C-505](specs/007.1-Parts-Catalog.md#c-505--braided-carbon-fibre-square-tube-075),
  [007.1 §Corrections](specs/007.1-Parts-Catalog.md#corrections-to-007),
  [007.2](specs/007.2-Printed-Parts.md#printed-parts) throughout,
  [008 §8.5](specs/008-Assembly.md#0085-arm-body),
  [008 §8.6](specs/008-Assembly.md#0086-differential),
  [DC-5](specs/009-Design-Completion.md#link-member-lengths),
  [DC-6](specs/009-Design-Completion.md#link-length-discrepancy-l4),
  [DC-9](specs/009-Design-Completion.md#performance-characterization),
  [DC-11](specs/009-Design-Completion.md#procurement-data),
  [009.1](specs/009.1-Performance-Characterization-Protocol.md),
  [009.2](specs/009.2-Test-Build-Manifest.md),
  `Hardware/Models/robot_assembly.scad` (new), `Hardware/Models/README.md`,
  `Hardware/Models/PART-INDEX.md`, `Hardware/Models/MANIFEST.csv`,
  `Hardware/Models/700-Differential/` (`diff_assembly.scad`, `diff_params.scad`, `diff_hardware.scad`,
  `720-001_DiffGearShaft.scad`, `render-meshes.rs`, `render-all.rs`),
  `Hardware/Models/400-EndArm/420-001_EndArmHub.stl`,
  `Hardware/Models/950-Tooling/GlueRig_EndArmHubToDiff_B.scad` (new) and its mesh,
  `Hardware/Models/Reference/superseded/GlueRig_EndArmHubToDiff_B_span309500.stl` (new).
- **Was:** [DC-11](specs/009-Design-Completion.md#procurement-data) gated ordering and printing, and it was
  open on five part identities the catalog could not pin, four differential findings with no seat to go to,
  and L3's far end, where [C-505](specs/007.1-Parts-Catalog.md#c-505--braided-carbon-fibre-square-tube-075)
  leaves the tube's far face 36.000 mm short of the J4 axis and no file presented the face it butts. The
  fan had no size and no part number; the Belt Directors were typed "Fabricate" in
  [007.5](specs/007-Bill-of-Materials.md#0075-arm-body) and printed everywhere else; layer height, wall
  count, infill and orientation were unpublished;
  [C-101](specs/007.1-Parts-Catalog.md#c-101--nema-17-stepper-09step) named a *recommended qualifying* part
  rather than a part of record and justified its holding torque as "legacy build record specifies
  0.52 N·m"; and two CAD bodies were recorded as BOM shortfalls. Motor stall was treated as the payload
  ceiling throughout, because [C-201](specs/007.1-Parts-Catalog.md#c-201--521-strain-wave-component-set)
  had transcribed everything from [`XB1-AS-C-32.pdf`](Hardware/Reference/XB1-AS-C-32.pdf) except its torque
  table. The model set held one assembly covering nine parts of seventy, so where parts sit relative to one
  another was recorded in prose or not at all, and [007.2](specs/007.2-Printed-Parts.md) pointed each part
  at the upstream archive its family came from rather than at a file.
- **Now:** **Every part in [007.1](specs/007.1-Parts-Catalog.md) resolves to an orderable product with a
  supplier link**, and all eleven of DC-11's sub-items are closed.
  *Identities.* The **fan is a 40 mm frame** — the CAD body `HDI-730-005_Fan` and the printed Fan Bracket
  agree on it independently — specified as Sunon `MF40101V1-1000U-A99` in
  [C-716](specs/007.1-Parts-Catalog.md#7-electronics-and-wiring), whose 4.5–13.8 V span makes it immune to
  whatever rail `J23` carries. The **Belt Directors are printed**, and the same measurement corrects the
  fit's direction: the Ø8.000 shank is the MR128 bore, so the bearings go *onto* it. **A print profile is
  published**, derived parameter by parameter from the features the parts must hold. **StepperOnline
  `17HM19-2004S` is the stepper of record**, adopted by decision because no manufacturer part number is
  recoverable — the design's own CAD carries the motor as an imported solid with no vendor identity, which
  was the last place one could have been held — with body length **48 mm exactly** and a two-sided
  constraint, the End Cap being epoxied to the Main Pivot before the motor is epoxied to it. **Neither
  CAD-vs-BOM mismatch is a missing row:** `HDI-311-006C_J2StatorHolderCap_ConeDrive` is a modelling
  division of the single printed `#200-002`, and `HDI-610-006_MotorShaftCoupler` is a different part from
  `#630-004` used as a generic hub.
  *Loads.* **The drives, not the motors, limit joint load.** At 52:1 the component set is rated **4–5 N·m
  continuous, 11 N·m start/stop, 24 N·m peak**; J2 reaches the continuous rating at ≈0.45 kg at the tool
  tip and start/stop at ≈1.45 kg, while the specified motor drives it to ≈16.7 N·m, so the motor can
  overload the drive without ever stalling. Holding torque is derived rather than inherited:
  [003](specs/003-Kinematics.md#static-gravity-torque) owns a worst-case static gravity table computed with
  the project's own `DH.torques_gravity`. The drawing also yields the axial interface, **23.5 mm between
  mounting faces**.
  *The differential's parts.* All four findings are adjudicated and none of them wanted a bore. The
  **thrust stack** is a washer stack between the Split Gear Top's base annulus and the Diff Keeper, on the
  10.423 mm of Diff Body B's Ø8 tube that stands proud of that base. The **MR85** seats by its OD 8 in the
  top 1.5 mm of `#720-002`'s Ø8 rod bore, which also fixes the CF rod: it stops on the bearing rather than
  flush with that face. The fifth **6703** is an assembly bearing that
  [008.6](specs/008-Assembly.md#0086-differential) step 8 turns one gear half against the other on. **The
  five `#720-005` 60 mm CF strakes are withdrawn** — no assembly step places them, the build record does
  not list them, and no slot in any of the nine printed parts will take one. **Two bearing counts were
  wrong and are corrected:** MR128 2 → **4** and 6703 5 → **6**, both corroborated by the build record
  [008.6](specs/008-Assembly.md#0086-differential) descends from.
  *The arm.* `robot_assembly.scad` composes the arm in the CAD kinematic frame, solving **every placement
  from a feature the part itself carries** and listing in `UNPLACED` any part whose position nothing fixes.
  It settles L3's far end by finding that **the part that row was opened on does not exist**: Diff Body A's
  own −x spigot is the same 20 × 20 R4 plug the End Arm Hub presents — 386.245 mm² against 386.068 in
  section over one bore of 131.7156 mm² against 131.7158, two parts in a million — so it is the tube's far
  end and points back down the forearm, and the Diff End Pulley facing the elbow sends the J4 axis along
  world z. The J4 and J5 crossing lands on the **J4 axis at the J4 station**, where J3 to the
  differential's own J4 axis measures the specified **307.500 mm** and the specified **243.0 mm C-505 cut
  laps the spigot by 15.000 mm**. **No part is missing and no cut length moves.**
  *The jig.* `950-Tooling/GlueRig_EndArmHubToDiff_A`/`_B` registers a Ø22.971 boss in the End Arm Hub's
  Ø22.990 J3 bore at one end and a Ø16.971 boss — a 6703's bore, its Ø23 race seating in Diff Body A — at
  the other, so it states J3 to J4 directly. As exported it stated 309.500 mm. The kinematic records are
  the design of record and a jig is derived from them, so the jig is what moves: `_B` is shortened
  **2.000 mm** across a prismatic stretch of its trough, clear of both registers and of the pair's lap, and
  is now generated from `GlueRig_EndArmHubToDiff_B.scad`.
  *The mirror.* [007.2](specs/007.2-Printed-Parts.md#printed-parts) links every row to the file
  `Hardware/Models/` holds that part as; `Hardware/Models/PART-INDEX.md` owns which file is which part and
  the `Model` column is generated from it.
  *The wall holes.* **The Diff Gear Shaft prints solid.** The twelve Ø0.2 wall holes its reference mesh
  carries are unbuildable and unused, so [007.2](specs/007.2-Printed-Parts.md#differential--0076) states
  the part's print state and `720-001_DiffGearShaft.scad`'s `wall_holes` flag defaults off to match. The
  harness gate already masks the ring the holes occupy, so it passes on the solid render unchanged.
- **Driver:** DC-11 gated ordering and printing — it is the item standing between the specification and a
  parts order — and most of what it held was answerable from geometry already in the repository rather than
  from a decision or a build. Answering the last of it needed the parts composed: a part in its own print
  frame cannot show a hole, and a subassembly placed by a bounding box is placed by a coincidence.
- **Status:** `[Provisional]` — DC-11 is left with one item, and it needs no part authored: the coupon
  print that validates [row d](specs/009-Design-Completion.md#procurement-data)'s profile, which is
  [009.2](specs/009.2-Test-Build-Manifest.md)'s.
- **Re-derive:** **Order against the corrected rows.** Ordering from
  [007.6](specs/007-Bill-of-Materials.md#0076-differential) as it stood lands two MR128 and one 6703 short
  at the bench. [C-503](specs/007.1-Parts-Catalog.md#c-503--carbon-fibre-strip-057--177) drops from 8
  pieces and a 48″ stick to 3 pieces and a **24″** stick. Any payload figure quoted against motor stall is
  superseded: the ceiling is the gearbox and roughly a third of the motor-derived number, so
  [009.1 Test 4.3](specs/009.1-Performance-Characterization-Protocol.md#test-43-rated-payload) is bounded
  at **1.0 kg** with that bound added as a stop condition, and
  [009.2](specs/009.2-Test-Build-Manifest.md)'s Stage 2 gate reads the drive's axial stack-up rather than
  end-cap stand-off. **Nothing dimensional moves on the robot**: no cut length, part dimension, link length
  or L4 value changes, and the 0.4665 mm by which the spigot axis sits off the tube's is unchanged. What is
  withdrawn is the span — `robot_assembly.scad` draws no void,
  [C-505](specs/007.1-Parts-Catalog.md#c-505--braided-carbon-fibre-square-tube-075)'s 283.5 mm alternative
  cut and [004](specs/004-Mechanical-Architecture.md#differential-interface)'s reading that the
  differential centre lands on the J5 station both go with it, and
  [009.2](specs/009.2-Test-Build-Manifest.md) loses a gate:
  [DC-12](specs/009-Design-Completion.md#wrist-pulley-rework) is the only authoring work the build now
  waits on. **A glue rig printed before this change is 2.000 mm long** and is not the tool
  [008.6](specs/008-Assembly.md#0086-differential) calls for; the as-exported mesh is kept under
  `Reference/superseded/`. Two [008.6](specs/008-Assembly.md#0086-differential) steps are corrected — step
  11 sent the 25 mm strakes to the Split Gear Bottom, which carries no slot, and step 23 left the Diff
  Keeper butted on the Split Gear with no room for the stack it retains — and `ROD_TOP` in
  `diff_assembly.scad` moves 1.5 mm with the End Pulley on it.
  **A `720-001` mesh rendered before this change carries the Ø0.2 wall holes**, the flag having defaulted
  on; re-render it before slicing. This closes the wall-hole question
  [CR-3A7](#cr-3a7-differential-detail-design-authored-as-parametric-openscad) left open.
- **Note:** *What made the composition renderable.* Three unrelated defects stopped a full render and each
  was cleared on its own terms. Exported meshes are not always surfaces CGAL can walk, so
  `render-meshes.rs` now puts each one through `scadmesh` as it is written — `settle` writes the mesh as
  OpenSCAD's own importer will read it, `repair` fills the gaps that reveals, and `pinch` opens any edge or
  vertex the surface still touches itself at — and stops on a part that fails, so the cache is renderable
  or there is no cache. `420-001_EndArmHub.stl` was not a closed 2-manifold at all, three of its four
  Ø3.000 holes being tangent to its Ø27.500 bore, and is corrected in place by `pinch`: 6 triangles added,
  no existing vertex moved, volume four parts in ten million larger. And surfaces the design has touching
  were drawn touching, which CGAL cannot union, so `diff_params.scad` defines `DRAW_JOINT = 0.001` mm and
  owns what it is for; the stand-ins are illustrations rather than part models and no seat, bore or part
  dimension derives from it. *Why the arm was drawn before it was landed.* The differential was first left
  out of the composition, then drawn in every direction its J4 axis could take, rather than placed on a
  reading — [003 §DH model](specs/003-Kinematics.md#denavithartenberg-model) put that axis across the arm
  and [004](specs/004-Mechanical-Architecture.md#differential-interface) fitted Body A to the gripper
  covers by a radius that bounds two perpendicular directions at once. Drawing it either way would have
  adopted an answer silently. The mating bore is what decided it — a belt passage is not a feature a tool
  arm repeats — and 004's gripper-cover argument is withdrawn there along with the four readings it
  produced. *Sizing.* Link 2 carries 2.520 kg of the robot's 4.79 kg of moving mass and its centre of mass
  acts 62 mm *behind* the J2 axis, so the unloaded arm needs about a twentieth of the specified motor's
  holding torque: motor sizing on this robot is set by payload and dynamics, not by holding its own weight
  up. *The drawing's silence.* The body-length tolerance
  [`XB1-AS-C-32.pdf`](Hardware/Reference/XB1-AS-C-32.pdf) was consulted for is not on it — the drawing
  fixes the component set internally and says nothing about how far its mating parts may sit from nominal —
  so the band is an assembly stack-up taken up on the Stator Holder all-thread, which
  [009.2](specs/009.2-Test-Build-Manifest.md) Stage 2 records.

### CR-3A18: Wrist pulleys re-cut to the specified tooth counts

- **Affects:** [004 §Wrist and differential](specs/004-Mechanical-Architecture.md#wrist-and-differential-j4j5),
  [004 §Differential interface](specs/004-Mechanical-Architecture.md#differential-interface),
  [007 §7.6](specs/007-Bill-of-Materials.md#0076-differential),
  [007 §7.7](specs/007-Bill-of-Materials.md#0077-end-arm-hub),
  [007.1 §3](specs/007.1-Parts-Catalog.md#3-belts-and-pulleys),
  [007.2](specs/007.2-Printed-Parts.md#printed-parts),
  [008 §8.6](specs/008-Assembly.md#0086-differential), [008 §8.9](specs/008-Assembly.md#0089-belts),
  [DC-3](specs/009-Design-Completion.md#wrist-reduction-ratio),
  [DC-12](specs/009-Design-Completion.md#wrist-pulley-rework),
  [009.1](specs/009.1-Performance-Characterization-Protocol.md),
  [009.2](specs/009.2-Test-Build-Manifest.md),
  `Hardware/Models/gt2_pulley.scad` (new), `Hardware/Models/robot_assembly.scad`,
  `Hardware/Models/400-EndArm/` (`external_pulley.scad`, `430-001_ExternalOuterPulley.scad`,
  `430-002_ExternalInnerPulley.scad`, all new; both meshes moved to `Reference/meshes/400-EndArm/`),
  `Hardware/Models/700-Differential/` (`720-004_DiffShaftPulley.scad` new; `diff_params.scad`,
  `720-001_DiffGearShaft.scad`, `720-003_DiffEndPulley.scad`, `730-001_DiffBodyA.scad`,
  `diff_assembly.scad`, `render-meshes.rs`, `render-all.rs`), `Hardware/Models/README.md`,
  `Hardware/Models/PART-INDEX.md`, `Hardware/Models/MANIFEST.csv`.
- **Was:** The model set carried the previous version's counts — 90T External pulleys and 40T
  differential inputs, netting 5.625:1 against an `AxisCal` of 86400 — so a wrist printed from it scaled
  every commanded J4/J5 angle by 2.4. The External pulleys existed only as meshes, and `diff_params.scad`
  held one measured 40T tooth ring.
- **Now:** `config="revised"` builds 108T External pulleys, an 80T Diff End Pulley, and a new 80T ring,
  `#720-004` Diff Shaft Pulley, keyed on the Diff Gear Shaft's 40T band; Diff Body A's pulley chamber is
  opened to clear them, widening it from 60.0 to 63.0 mm, and its M3 screws move outboard of the ring.
  Every printed GT2 ring derives from `gt2_pulley.scad`. `render-all.rs` counts the revised teeth on the
  rendered meshes, checks the assembly's placing extents against the renders, and requires Diff Body A
  and `#720-004` not to intersect; `robot_assembly.scad` asserts Diff Body A inside the forearm skin.
  `config="previous"` and its `dist` gates are unchanged.
- **Driver:** Realize [CR-3A8](#cr-3a8-wrist-tooth-count-decomposition-design-status-consolidated-into-009)'s
  decomposition so the printed wrist matches `AxisCal`.
- **Status:** `[Specified]` — DC-12 is closed. The External pulleys' clearance at the elbow is not placed
  by any file in the repository and is confirmed on the first build with the belt lengths.
- **Re-derive:** Print every wrist pulley and Diff Body A from `config="revised"`; a `config="previous"`
  print does not match `AxisCal`. [008.6](specs/008-Assembly.md#0086-differential) step 13 now sets
  `#720-004` in Body A before the shaft enters it. [009.2](specs/009.2-Test-Build-Manifest.md) has no
  authoring gate left on the wrist.

### CR-3A19: L1 specified from the base stack; the doubled clamp withdrawn; 6810s allocated to their seats

- **Affects:** [001 §5](specs/001-Overview.md#5-design-lineage), REQ-STR-4 in
  [002](specs/002-Requirements.md), [003 §Link lengths](specs/003-Kinematics.md#link-lengths),
  [004 §Base mounting plate](specs/004-Mechanical-Architecture.md#base-mounting-plate),
  [004 §Wrist and differential](specs/004-Mechanical-Architecture.md#wrist-and-differential-j4j5),
  [006 §Firmware defaults](specs/006-Firmware-and-Calibration.md#firmware-defaults-defaultsmake_ins),
  007 [§7.2](specs/007-Bill-of-Materials.md#0072-base),
  [§7.3](specs/007-Bill-of-Materials.md#0073-harmonic-drive-motors),
  [§7.4](specs/007-Bill-of-Materials.md#0074-main-pivot),
  [§7.8](specs/007-Bill-of-Materials.md#0078-external-gear),
  [§7.9](specs/007-Bill-of-Materials.md#0079-external-gear-mount--differential-motors) and
  [aggregate](specs/007-Bill-of-Materials.md#aggregate-hardware-quantities-whole-robot),
  007.1 [C-101](specs/007.1-Parts-Catalog.md#c-101--nema-17-stepper-09step),
  [C-201](specs/007.1-Parts-Catalog.md#c-201--521-strain-wave-component-set),
  [§4](specs/007.1-Parts-Catalog.md#4-bearings), [§6](specs/007.1-Parts-Catalog.md#6-fasteners) and
  [§Corrections](specs/007.1-Parts-Catalog.md#corrections-to-007),
  007.2 [§Totals](specs/007.2-Printed-Parts.md#totals) and
  [§Print fits](specs/007.2-Printed-Parts.md#print-fits) (new),
  008 [.2](specs/008-Assembly.md#0082-base), [.3](specs/008-Assembly.md#0083-harmonic-drive-motors),
  [.4](specs/008-Assembly.md#0084-main-pivot), [.5](specs/008-Assembly.md#0085-arm-body),
  [.7](specs/008-Assembly.md#0087-end-arm-hub) and [.8](specs/008-Assembly.md#0088-external-gear),
  [009](specs/009-Design-Completion.md),
  009.1 [§3.1](specs/009.1-Performance-Characterization-Protocol.md#test-31-mounting-face-to-j2-axis) and
  [§3.3](specs/009.1-Performance-Characterization-Protocol.md#test-33-j3-drive-stack) (new),
  [009.2](specs/009.2-Test-Build-Manifest.md), [010](specs/010-Versioning.md).
  Under `Hardware/Models/`: `robot_assembly.scad`, `print_fit.scad` (new), `render-check/` (new),
  `README.md`, `PART-INDEX.md`, `MANIFEST.csv`; `100-Base/110-002_BaseStatorHolder.scad` (new);
  `200-ArmBody/200-002_PivotStatorHolder.scad` (new); `400-EndArm/`'s External pulleys; `500-ExternalGear/`
  (`exgear_assembly.scad`, `exgear_assembly.view.json`, `511-001_ExGearMotorEndCap.scad` and
  `511-002_ExGearStatorHolder.scad`, all new; `510-001_ExternalGear.stl`, pinched); `600-StrainWave/`
  (`630-005_FlexSplineAttach.scad`, `630-006_FlexSplineCap.scad` and `c201_spline_seat.scad`, all new);
  `700-Differential/` (every part file, `diff_params.scad`, `diff_assembly.scad`, `diff_bevel.scad` and
  `render-meshes.rs`; `parts.json` and `diff_assembly.view.json`, new); `render-all.rs` in `100-Base`,
  `200-ArmBody`, `500-ExternalGear` and `600-StrainWave` (new) and in `700-Differential`;
  `950-Tooling/fit_coupon.scad` (new); the six meshes the new sources replace, moved to `Reference/meshes/`.
- **Amends:** [CR-3A2](#cr-3a2-bolted-base-and-doubled-base-clamp) (the doubled clamp; the bolted base
  stands),
  [CR-3A9](#cr-3a9-base-mounting-plate-specified-two-link-datums-withdrawn-two-model-mirrors-replaced)
  ("doubled clamp resolved from geometry": the 97.000 mm shoulder, the Base Long bottoming on nothing, the
  15.000 mm rise, and the clamp-screw and M3 nut counts of 2 and 45),
  [CR-3A12](#cr-3a12-l4-specified-along-the-arm-the-dh-d-corroboration-withdrawn) (L1's `[TBD]` status),
  [CR-3A6](#cr-3a6-parts-catalog-and-printed-parts-list-added-bom-made-orderable) (its 6810 correction from
  7 to 8).
- **Was:**
  - **Base.** L1 = 235.20 mm on the authority of `Firmware/Defaults.make_ins`, against two 15.000 mm clamps
    on a 97.000 mm shoulder that was held to set the Base Long's height. The CAD's single-clamp chain put
    J2 at 231.200 mm and the doubled stack at 246.200 mm, neither of them L1, and DC-13 waited on a
    first-build measurement of height and clamp count together.
  - **6810s.** 7.2 listed two, "one per Base row", and C-401 totalled 8. 008.7 step 1 put a 6810 in each
    Axis Intersection half, against 7.7's two 6807s, and no step in 008 consumed 7.9's. J1's and J2's far
    6810 was pushed off its shoulder on assembly and tapped back (008.4 step 9c, 008.5 step 2), and J3's
    was pressed "~38 mm" with the same instruction (008.8 step 5).
  - **Strain-wave adapters.** #511-001, #630-005, #630-006 and the three Stator Holders (#110-002,
    #200-002, #511-002) were the HD set's meshes. C-201's table gave the circular spline 6 × Ø4.5 holes on
    Ø44 and the Attach 6 × Ø3.5, and [DC-1](specs/009-Design-Completion.md#strain-wave-component-set) was
    closed on the holders and the Attach matching the drawing. Each holder took 4 M2 × 16 mm bolts, and
    the spline 2 M3 × 12 mm bolts (008.4 steps 10–11, 008.5 steps 4–5).
  - **Fits.** Every printed part was drawn line to line against its mates, which a printed part, slightly
    oversize, does not go together on. The External Gear's mesh touched itself on one ring, so CGAL
    refused it in any boolean.
  - **Differential.** `diff_params.scad` defaulted to `config="previous"`, so a file opened or rendered
    without `-D` showed the reference parts. The Diff Gear Axle's Ø9 boss ran 1.84 mm into the Diff Gear
    Shaft's front MR128, and its rod bore was a slip fit that left 0.35 mm of wall. Diff Body B overlapped
    the toes of the three bevel crowns that turn in it, and `diff_assembly.scad` recorded those overlaps
    rather than designing them out. The shaft's Ø19 shoulder ran 0.17 mm into Body B's rear 6703, and the
    Split Gear Bottom's crown-bore shoulder 0.42 mm into the column 6703. Four shoulders that locate a
    bearing by its outer race bore on its inner race as well: Body A's Ø26 under the 6705, the Split Gear
    Bottom's Ø18 under the column 6703, and each Split Gear half's Ø8.5 under its MR128. The 6703 between
    the Split Gear's halves was drawn on the Top's pocket floor, across both races.
- **Now:** Each part's geometry is stated in its file's header; this entry records the decisions and the
  evidence for them.
  - **L1 = 231.500 mm, the printed stack**
    ([004 § Base mounting plate](specs/004-Mechanical-Architecture.md#base-mounting-plate)), **and the
    clamp is not in it.** Sectioning the CAD bodies shows the Base Long and the Base Mount Bottom sharing
    material over r 33–36 mm at 98.000 mm, so the Base Long bottoms on the mount. The clamp seats on its own
    shoulder below; its Ø74.500 bore equals the outer face radius of the strakes it squeezes. The CAD
    chain's 231.200 mm is 0.300 mm short because its Base Long body is the earlier, 95.700 mm revision.
  - **The spigot takes one clamp; the doubled clamp is withdrawn.** A second would ride on the first and
    lift the Base Long 14.000 mm off its seat, to no stop. The HD build notes list one clamp, one
    M3 × 20 mm bolt and one M3 nut. The wiki's `Dynamics.md` lists a "double base clamp" among the features
    "specific to the Dexter HDI that was measured": a deviation on that unit, not the design. The bolt
    runs across the clamp's split into a hex pocket for the nut (the build notes' "M3 Washer" there is a
    slip); the ±35.540 mm holes are six axial Ø3.5 mm holes in the Base Long, not clamp-bolt holes.
  - **The firmware's 235.20 mm is superseded.** No seated stack of these parts reproduces it, nor does the
    doubled-clamp unit, whose second clamp has no stop. HDI-007010's J1 `d` = 250.101 mm, 14.9 mm above
    it, fits that unit having carried a second clamp, but is not a reading of L1
    ([003](specs/003-Kinematics.md#denavithartenberg-model)).
  - **The robot takes seven 6810s** ([C-401](specs/007.1-Parts-Catalog.md#4-bearings)). That is the
    figure CR-3A6 corrected from, reached by a different sum: CR-3A6's count took 7.3 once and 7.2 twice.
    Each seat decides its bearing:
    - The Base Long's upper bore, Ø65 × 7 mm flush with its top face, takes the Base Motor End Cap's
      bearing, which is 7.3's. Only the bearing in its lower bore is 7.2's: Ø65 for 35.5 mm onto a Ø60
      shoulder, the build notes' "about 1½″ down" seat, which sets no height. The build notes list three
      6810s for the Main Pivot: two end caps and one Base Long.
    - `#410-001`'s Axis Intersection seat is Ø47.000 × 7 mm, a 6807; the build notes' "2 - 6810
      Bearings" under the End Arm Hub is a slip that 008.7 inherited.
    - The `#520-002` Ex Gear Mount Top's Ø65.0 × 7 mm seat, bored from its underside, is the third support
      of J3's output, around the circular spline that turns with the Stator Holder and the External Gear.
      The build notes do not install it; the seat decides it.
  - **J3's stack closes on two revised prints.** Placed from its seats, J3's upper 6810 ran into the Flex
    Spline Attach's flare, and the drive stood higher on its motor than on its Stator Holder. `#511-001`
    deepens the motor seat; `#630-005` removes the flare and lowers the hub face by `hub_drop`.
    `exgear_assembly.scad` (new) places the group from the parts' own seats, computes the drop from
    `MOTOR_LEN`, and asserts and echoes the closure and every clearance. J1 and J2 print the same Attach
    at no drop: their far 6810, which sat 0.2 mm into the flare and was tapped back, now runs free on the
    land, retained by the #6 washers, and their all-thread nuts take up the drive's span.
  - **C-201 is seated to its drawing**
    ([C-201](specs/007.1-Parts-Catalog.md#c-201--521-strain-wave-component-set) owns the values and the
    meshes' mismatches). The three Stator Holders and the Flex Spline Cap are now OpenSCAD source whose
    `config="previous"` reproduces the mesh within 0.026 mm and 0.005 mm. In `config="revised"`, one
    shared seat, `c201_spline_seat.scad`, gives each holder a pilot for the spline's step and six M3
    screws into captive nuts, and the Attach and the Cap clamp the flexspline hub on its bore and holes
    before the Attach goes on the motor. The Ex Gear Stator Holder seats on its keys' end chamfers, 3 mm
    higher than first placed, where it cut the gear's bore.
  - **Every printed part's `config="revised"` draws its fits with print clearance** from one library,
    `print_fit.scad`, by the classes in [007.2 § Print fits](specs/007.2-Printed-Parts.md#print-fits).
    `config="previous"` draws none, so no dist gate moves. The fit coupon is a model, and the slicer's
    dimensional compensation goes to zero, since the clearances carry the machine's fit.
  - **The differential defaults to `config="revised"`**
    ([004](specs/004-Mechanical-Architecture.md#wrist-and-differential-j4j5)), with `previous` selected by
    `-D`, and `parts.json` is its one part list. In `revised`:
    - Diff Body B stands the running clearance off the volume each of the three bevel crowns' teeth sweep,
      by moving each facing surface whole, so no cut leaves a ridge (`730-002_DiffBodyB.scad`, TOE
      CLEARANCE).
    - The Diff Gear Axle's boss, the spacer that 008.6 step 21's rod stops on, seats on the inner race of
      the Diff Gear Shaft's front MR128: the shaft's front journal is shorter by `front_drop()`, and Body
      B's front seat that much deeper. The boss body grows, and the rod bore becomes a press fit, so its wall goes
      from 0.35 to 1.15 mm (`720-002_DiffGearAxle.scad`).
    - Each bearing shoulder bears on one race: outer-race shoulders are bored to `shoulder_bore()`, and
      inner-race shoulders stop at the far faces `diff_params.scad` carries from Body B's seats.
  - **Every model group checks itself.** The shared `render-check` crate reads the clearances from
    `print_fit.scad` and probes each fit a part's header lists, in a `render-all.rs` per group. The 500
    script checks the Ex Gear Stator Holder by sections where its keys fit line to line; the 700 script
    requires Body B to render empty against its neighbours and against the three tooth zones grown to
    just under the running clearance. `510-001_ExternalGear.stl` is pinched so CGAL accepts it; the Models
    README records the pairs that still fail.
  - **The section view is reusable.** `scadmesh view` (openscad-tools) builds a section viewer for any
    viewable assembly from a sidecar whose numbers come from the assembly's echoes:
    `exgear_assembly.view.json` and `diff_assembly.view.json`, with label toggles (REQ-W-6 in
    openscad-tools).
- **Driver:** DC-13 could not be closed by a measurement whose outcome depended on how many clamps a
  builder fitted. A link length has to rest on positive stops that the parts define. A bearing row that no
  step consumes, or a step that consumes a bearing no row lists, is an order that arrives short or long at
  the bench. A bearing that is tapped back on every build, one that cannot reach its journal, a fit drawn
  with no room for a printed surface's error, and a gear that turns through the body around it are faults
  the printed parts must design out, not steps a builder repeats.
- **Status:** `[Specified]` — [DC-13](specs/009-Design-Completion.md#base-height-and-l1) is closed. The
  built height is confirmed under
  [DC-9](specs/009-Design-Completion.md#performance-characterization)'s base checklist. J3's stack closes
  in `exgear_assembly.scad`, whose asserts hold it for the measured motor length; the fit is confirmed on
  the first built J3 by
  [009.1 § 3.3](specs/009.1-Performance-Characterization-Protocol.md#test-33-j3-drive-stack). Both
  halves of C-201 are seated: the circular spline in all three holders, and the flexspline hub between
  the Attach and the Cap. [DC-1](specs/009-Design-Completion.md#strain-wave-component-set) stays closed.
- **Re-derive:**
  - **003, 004, 006** carry L1 = 231.50 mm. 004 takes the single clamp and the stack table and drops the
    Base open item; 006's `LinkLengths` block calls out the second deviation from the shipped file, which
    is not edited, per CR-3A12. The derived maximum reach does not include L1 and is unchanged.
  - **007, 007.1.** #100-001 goes to qty 1; M3 × 20 mm to 5, M3 × 12 mm to 34 and M3 nuts to 62, the last
    two with the spline's 6 screws and 6 nuts per joint in 7.3 and 7.8. C-401 carries 7 with its
    breakdown, and the corrections table loses its 6810 row and C-401 note. C-201's table takes the
    drawing's hole sets and ties each mating feature to its printed part, and its model-set check states
    both mismatches; C-101's body-length row says how each joint closes the drive. C-502 draws
    `#710-001`'s slots at the press clearance and points to the coupon.
  - **007.2, `PART-INDEX.md`** point the six new sources at their `.scad` files. 007.2 prints them from
    `config="revised"` and the differential from the default, counts 108 printed pieces (119 with
    tooling), adds § Print fits, and zeroes the slicer's compensation in the print profile.
  - **008.** 008.2 step 6 places the clamp's nut. 008.3 measures J3's motor before its Attach is printed,
    seats and clamps the hub before the Attach goes on the motor (steps 4–7), sets the wave generator's
    depth from the flex spline's mounting face (step 10), and mounts each spline in its holder (step 12).
    008.4, 008.5 and 008.8 link that step instead of repeating it, so 008.4's later steps renumber to
    12–16 and 17, and 007.1's C-101 row, 008.2 and 009.1 cite them. 008.4 steps 4 and 9 name the end caps
    and seat both Base Long bearings, and step 17 installs one clamp. The tap-back steps go, and the
    washers of 008.4 step 9d and 008.5 step 3 retain the free-running inner race. 008.6 step 11 points to
    the coupon, 008.7 step 1 inserts 6807s, 008.8 step 8 seats the keys, and 008.8 step 13 presses the 7.9
    bearing into the Ex Gear Mount Top.
  - **009, 009.1, 009.2.** 009.1 § 3.1 measures from the plate's top face (the Base Mount Bottom's mounting
    face) and becomes a pass/fail confirmation of L1; § 3.3 confirms J3's closure on the built joint, and
    008.8, 009 and 009.2's Stage 4 point to it. 009's DC-11(d) row and 009.2's Stage 0 point to the coupon
    rather than state slot sizes. 009.2's Stage 2 gate loses J3 to Stage 4, whose draw list loses a
    repeated 007.9 line. Two restatements become links: 007.2's L3 rig paragraph to DC-11(h), and
    DC-11(h)'s spigot section to 004.
  - **Models.** `robot_assembly.scad` seats the Main Pivot on the printed Base Long and asserts that the
    stack sums to L1. `exgear_assembly.scad` draws the revised holder, the spline and the Cap from their
    sources. `diff_assembly.scad` takes the viewable shape and a `part` id per export, reads Body B's
    front seat from 720-001's `front_drop()` and `front_seat_floor()`, and asserts that the boss's tip is
    the front MR128's face; `diff_bevel.scad`'s `BEVEL_ZONE` and 720-001's `crown_zone()` state the tooth
    zones the gates grow. Each part's header lists its fits and classes, and `render-meshes.rs` builds in
    `config="revised"` unless told otherwise. The Models README recounts its parts and files and points to
    the `render-all.rs` files for the gates' figures.

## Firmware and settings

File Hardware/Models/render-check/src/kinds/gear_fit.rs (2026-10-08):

//! `gear_fit`: a Stator Holder against the External Gear. CGAL cannot take this
//! pair at zero clearance: the keys then fit the slots line to line, and a
//! boolean over coincident faces fails and returns an operand. The fit is
//! checked where it is made instead, in each shared plane below the gear's end,
//! between the spigot's outline (the holder's outer loop) and the socket's (the
//! gear's inner loop). Drawn at zero clearance the two must be the same
//! section; at the slip clearance the spigot must stand in by it all round.
//! Above the gear's end the holder has nothing the gear could reach.
//!
//! Fields: `scad`, `config`, `nominal_out` and `fitted_out` (binary meshes, the
//! first drawn with `FIT_SLIP=0`), `gear` (the gear's mesh), `echo_file` and
//! `echo_name` (the height of the gear's end in the holder's frame), `sections`
//! (holder heights), `outline` (the spigot's outline length in mm) and `tol`
//! (section-area agreement in mm2: 0.01 mm of mean offset over `outline`,
//! with faceting alone accounting for about 1 mm2), and optionally
//! `print_fit`.

use super::fits::{clearances, DEFAULT_LIBRARY};
use super::{echoed_number, render_extra, Env, Fields, Report};
use anyhow::{Context, Result};

const BINARY: [&str; 2] = ["--export-format", "binstl"];

pub fn run(env: &Env, f: &Fields, rep: &mut Report) -> Result<()> {
    let (scad, config) = (f.str("scad")?, format!("config=\"{}\"", f.str("config")?));
    let (nominal, fitted) = (f.str("nominal_out")?, f.str("fitted_out")?);
    render_extra(env, scad, nominal, &[config.clone(), "FIT_SLIP=0".into()], &BINARY, rep)?;
    render_extra(env, scad, fitted, &[config], &BINARY, rep)?;
    let (slip, _) = clearances(env, f.str_or("print_fit", DEFAULT_LIBRARY))?;
    let on_gear = echoed_number(&env.tools.read(f.str("echo_file")?)?, f.str("echo_name")?)?;
    let gap = f.f64("outline")? * slip;
    for z in f.f64_list("sections")? {
        let drawn = loop_areas(env, nominal, "z", z)?.first().copied().context("no loop in the nominal section")?;
        let spigot = loop_areas(env, fitted, "z", z)?.first().copied().context("no loop in the fitted section")?;
        let socket = *loop_areas(env, f.str("gear")?, "x", on_gear - z)?.get(1).context("the gear section has no socket loop")?;
        let (lead, tol) = (format!("stator spigot at zero clearance is the gear's socket at holder z {z}"), f.f64("tol")?);
        rep.record(&format!("{lead} ({drawn:.2} vs {socket:.2} mm2)"), (drawn - socket).abs() < tol);
        let stands = format!("stator spigot stands in by the slip clearance at holder z {z}");
        let by = socket - spigot;
        rep.record(&format!("{stands} ({by:.2} mm2, ~{gap:.1} expected)"), (by - gap).abs() < gap / 2.0);
    }
    Ok(())
}

/// The areas of a section's loops, largest first.
fn loop_areas(env: &Env, stl: &str, axis: &str, at: f64) -> Result<Vec<f64>> {
    let at = format!("--at={at}");
    let (_, json) = env.tools.scadmesh(&["slice", stl, "--axis", axis, &at])?;
    let mut areas: Vec<f64> =
        json["loops"].as_array().context("slice emitted no loops")?.iter().filter_map(|l| l["area"].as_f64()).map(f64::abs).collect();
    areas.sort_by(|a, b| b.total_cmp(a));
    Ok(areas)
}

#[cfg(test)]
mod tests {
    use crate::kinds::testing::*;
    use serde_json::{json, Value};

    fn fields() -> Value {
        json!({"scad": "h.scad", "config": "revised", "nominal_out": "out/n.bin.stl", "fitted_out": "out/f.bin.stl",
               "gear": "g.stl", "echo_file": "out/a.echo", "echo_name": "stator_on_gear",
               "sections": [6], "outline": 100, "tol": 2.3})
    }

    fn fake(fitted_area: f64) -> Fake {
        let mut f = Fake::new();
        f.files.insert("../print_fit.scad", "FIT_SLIP = 0.2;\nFIT_PRESS = 0.1;\n");
        f.files.insert("out/a.echo", "ECHO: stator_on_gear = 20\n");
        f.by_path.push(("n.bin.stl", json!({"loops": [{"area": 100.0}]})));
        f.by_path.push(("f.bin.stl", json!({"loops": [{"area": fitted_area}]})));
        f.by_path.push(("g.stl", json!({"loops": [{"area": 900.0}, {"area": 100.0}]})));
        f
    }

    #[test]
    fn a_spigot_that_stands_in_by_the_slip_clearance_passes_both_tests() {
        let f = fake(80.0);
        let o = check("gear_fit", fields(), &f);
        assert!(o.ok, "{}", o.output);
        assert!(o.output.contains("is the gear's socket at holder z 6 (100.00 vs 100.00 mm2)"), "{}", o.output);
        assert!(o.output.contains("stands in by the slip clearance at holder z 6 (20.00 mm2, ~20.0 expected)"), "{}", o.output);
        assert_eq!(f.calls()[0], "openscad -o out/n.bin.stl -D config=\"revised\" -D FIT_SLIP=0 --export-format binstl h.scad");
        assert!(f.calls().contains(&"scadmesh slice g.stl --axis x --at=14".to_string()), "{:?}", f.calls());
    }

    #[test]
    fn a_spigot_with_no_clearance_or_off_its_seat_fails() {
        let o = check("gear_fit", fields(), &fake(100.0));
        assert!(o.output.contains("PASS  stator spigot at zero") && o.output.contains("FAIL  stator spigot stands in"), "{}", o.output);
        let mut off = fake(80.0);
        off.by_path[0].1 = json!({"loops": [{"area": 160.0}]});
        assert!(check("gear_fit", fields(), &off).output.contains("FAIL  stator spigot at zero"));
    }

    #[test]
    fn a_missing_loop_or_echo_is_an_error() {
        let mut none = fake(80.0);
        none.by_path[0].1 = json!({"loops": []});
        assert!(check("gear_fit", fields(), &none).output.contains("no loop in the nominal section"));
        let mut one = fake(80.0);
        one.by_path[2].1 = json!({"loops": [{"area": 1.0}]});
        assert!(check("gear_fit", fields(), &one).output.contains("no socket loop"));
        let mut bare = Fake::new();
        bare.files.insert("../print_fit.scad", "FIT_SLIP = 0.2;\nFIT_PRESS = 0.1;\n");
        assert!(check("gear_fit", fields(), &bare).output.contains("no file out/a.echo"));
    }
}

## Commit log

2026-07-28 Docs and BOM assembly consolidation (#1)
    * Add consolidated BOM and assembly specs for Dexter HD
    Reconciles the scattered Google Sheets BOM and prose wiki build notes
    into a single specs/ set: 002-Bill-of-Materials.md (per-subassembly
    parts tables, aggregate hardware order quantities, sourcing notes) and
    003-Assembly.md (corrected, numbered assembly procedures cross-referenced
    to the BOM). Flags the harmonic drive flex spline/wave generator/stator
    gear as never fully specified upstream (marked NOT DESIGNED in the
    source PBS spreadsheet), which is the actual long-lead sourcing blocker.
    * Retarget spec set to Dexter HDI; add firmware/calibration spec
    Retargets 001-Overview, 002-Bill-of-Mate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
    [100-001_BaseClamp.stl, 100-002_BaseCodeDisc.stl, 100-003_PivotSkirt.stl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]
2026-07-29 Close DC-1: confirm strain-wave component set and cross-check dimensions (#4)
    * Close DC-1: confirm strain-wave component set and cross-check dimensions
    Confirms HanZhen XB1-AS-C-32(14)-52 as the quoted part (USD 120/set,
    9-12 week lead), records its mating dimensions from the manufacturer
    drawing, and cross-checks them against the printed adapter STL
    geometry to verify no scale mismatch. Updates specs 004, 007, 007.1,
    007.2, and 009 to reflect the set as Specified instead of TBD.
2026-09-03 Design Completion 2 - Differential detail design (#5)
    # CR-3A7: Differential detail design authored as parametric OpenSCAD
    - **Affects:** [004 §Wrist and differential](specs/004-Mechanical-Architecture.md#wrist-and-differential-j4j5),
    [003 §Link lengths](specs/003-Kinematics.md#link-lengths),
    [007.2 §Differential](specs/007.2-Printed-Parts.md#differential--0076),
    [008.6](specs/008-Assembly.md#0086-differential),
    [009 DC-2/DC-5/DC-6/DC-9/DC-11](specs/009-Design-Completion.md),
    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
    [710-001_SplitGearTop.scad, 710-001_SplitGearTop.stl, 710-002_SplitGearBottom.scad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]
2026-09-06 DC-3: Specify wrist reduction ratio (#6)
    * Consolidated duplicate status information in spec files.
    * Removed more duplicate info and added tool to check for similar instances going forward.
    * Consolidated list of changes.
    [diff_params.scad]
2026-09-11 DC-4 Base plate hole pattern (#7)
    Closes DC-4. Recorded as CR-3A9 in CHANGES.md.
    The branch is named for DC-4, but closing it required measuring the base chain and the wrist, and that turned up work in three other items. Net change against version-3 below.
    Base plate — DC-4 closed
    The robot-side hole pattern DC-4 was opened to transfer is exactly recoverable — but not from the file the mirror held as that part. That file had no fastener features at all.
    Pattern 8 × Ø6.000 mm through the mount's 150 × 150 × 10 mm flange
    Centres (±12.500, ±62.500) and (±62.500, ±12.500) — pairs on the four edges, not a bolt circle, unchanged by a 90° rotation of the robot on its plate
    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
    [110-001_BaseMountBottom.stl, 110-004_BaseMountingPlate.scad, 200-001_ArmBody.stl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]
2026-09-14 Relocate spec content and close design completion tasks (#8)
    - Closed out DC-5
    - Moved spec content from 009-Design-Completion.md to owning docs
    - Replaced 6 closed DC items with stubs and cross-references
    - Updated 007.1 parts catalog, 007.2 printed parts, 008 assembly specs
    - Verified link consistency and check-specs validation
    - Updated Hardware/Models docs and PART-INDEX for relocated section
2026-09-16 DC-6: L4 wrist separation (#9)
    * DC-6: Specify L4 as the along-arm wrist separation
    L4 is 39.50 mm, the along-arm separation of the J4 and J5 stations. The
    convention follows from the GLTF kinematic chain: taking only the
    along-arm component of each span reproduces the firmware's L3 to the
    micron and L2 to 3 um, so a link length is that component and the
    across-arm offset is not represented in a five-length model.
    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
    [MANIFEST.csv, diff_assembly.scad, diff_params.scad]
2026-09-16 Resolve DC-7: Motor Control PCB connector map and power-on test procedure (#10)
    Recovered connector-to-joint mapping from schematic (09011-00135-A.PDF):
    - J1-J6 stepper channels follow firmware axis order (Base, End, Pivot, Angle, Rotate), not joint numbers
    - J7-J13 opto headers follow the same channel order (J7 Base, J8 Rotate, J10 Angle, J11 Pivot, J12 End)
    - J24 main power input (pins: VIN1/GND1/VIN2/GND2); J23 fan through F7 (12V); J25 tool logic (ground/+5V)
    - Tool interface: Yellow on J24 pin 1 (unregulated input), White on J24 pin 2 (second ground — cross-version hazard)
    - J14-J17 are differential analog inputs, not tool connectors
    - J9, J18 are MicroZed carriers; J20, J21 FPGA AUX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
2026-09-17 DC-8: Power supply specified
    DC-11(j) closed by decision; spawned DC-14 for power inlet mounting.
    The KPJX-PM-4S receptacle is panel-mount. The build list has no panel, and
    the only candidates — Wire Entry left/right (18mm × 29.7mm × 43.7mm) — have
    no void larger than ~Ø6, smaller than a 4-pin DIN body. Tracked as new item
    DC-14 (P2, [Provisional]).
    Wire Entry pair is itself unplaced: listed in 007.10 and 007.2, but no step
    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
2026-09-17 DC-10: Calibration job files restored from repository history (#13)
    The two job files that drive 006 Steps 2-3 were not missing from the public
    repo. They were committed with the design and deleted from it in October 2020 —
    Find_Index_Pulses_HDI.dde at e4a3a0d, Setup_Find_Index_Home_HDIv2.dde at
    1b121ce — in a run of six pure deletions that added nothing in their place.
    Both are restored from that history.
    Neither is a thin wrapper over the calibration engine in dde/low_level_dexter/,
    as DC-10 held. The index-eye search, the scan thresholds and the home-offset
    arithmetic are in the job files themselves, and every routine 006 Step 3 names
    — Check_Eye_Order, Center_Eye, Find_Idx_Eyes*,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
2026-09-26 DC-11: Close 11 procurement data items (#14)
    * DC-11: Part identities, motor sizing and three differential placements
    DC-11 gated ordering and printing on eleven sub-items. Nine are answered here,
    all from geometry and documents already in the repository rather than from a
    decision or a build.
    Four part identities resolve against the model set. The fan is a 40 mm frame —
    HDI-730-005_Fan and the printed Fan Bracket agree on it independently —
    specified as Sunon MF40101V1-1000U-A99, whose 4.5-13.8 V span makes it immune
    to whatever rail J23 carries. The Belt Directors are printed, not fabricated,
    and the same measurement reverses the fit: the Ø8.000 shank is the MR128 bore,
    so the beari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
    [420-001_EndArmHub.stl, 720-001_DiffGearShaft.scad, GlueRig_EndArmHubToDiff_B.scad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]
2026-09-26 DC-12: Re-cut the wrist pulleys to the specified tooth counts (#15)
    config="revised" now builds the 16T -> 108T || 40T -> 80T train that
    AxisCal = 86400 assumes; config="previous" and its dist gates are unchanged.
    - 430-001/002 External pulleys: new .scad sources keeping each mesh's hub
    and adding a 108T rim; the meshes move to Reference/meshes/400-EndArm/.
    - 720-003 Diff End Pulley: 40T -> 80T.
    - 720-004 Diff Shaft Pulley (new): 80T ring keyed on 720-001's 40T band,
    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
    [430-001_ExternalOuterPulley.scad, 430-001_ExternalOuterPulley.stl, 430-002_ExternalInnerPulley.scad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]
2026-10-05 DC-13: Specify L1 from the base stack and seat the bearings, splines and fits it rests on (#16)
    * DC-13: Specify L1 from the base stack and close J3's external gear stack
    L1 is 231.50 mm, the height the seated base stack produces; the firmware
    file's 235.20 mm and the doubled base clamp are withdrawn. The 6810s are
    allocated to the seats that take them, and J3's stack now closes.
    - L1: Base Long bottoms on the Base Mount Bottom at 98.000; one clamp,
    outside the axial stack. 003, 004, 006 and 009.1 carry 231.50, and
    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
    [110-002_BaseStatorHolder.scad, 110-002_BaseStatorHolder.stl, 200-002_PivotStatorHolder.scad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]
2026-10-08 Common render script with parallel render (#17)
    * Add render.rs: parallel mesh build and --verify for 700-Differential
    One program reads a per-group render.json, plans a job graph and runs
    independent OpenSCAD renders concurrently. --meshes replaces render-meshes.rs
    and parts.json; --verify ports the 700-Differential checks (render, dist_gate,
    clone, counts, diameters, fits, extents, interference, keepout). Specified in
    specs/009.3-Render-Program.md.
    * Port --verify of 100-Base, 200-ArmBody, 500-ExternalGear, 600-StrainWave
    Adds the seat, probes, face, gear_fit, clash and plate kinds, cross-group
    waits (group/*), and render.json for four more groups. All groups pass on
    real tools. The old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
    [110-004_BaseMountingPlate.scad, 720-001_DiffGearShaft.scad, 720-003_DiffEndPulley.scad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]
2026-11-03 Scadify: convert every mesh-only printed part to OpenSCAD (#30)
    * Scadify 100-Base models (#18)
    Parts converted to OpenSCAD
    Each part has a .scad source with previous (zero-clearance recreation, gated against the reference mesh) and revised (print-fit) configurations.
    Part Name File
    100-001 Base Clamp Hardware/Models/100-Base/100-001_BaseClamp.scad
    100-002 Base Code Disc Hardware/Models/100-Base/100-002_BaseCodeDisc.scad
    100-003 Pivot Skirt Hardware/Models/100-Base/100-003_PivotSkirt.scad
    110-001 Base Mount Bottom Hardware/Models/100-Base/110-001_BaseMountBottom.scad (with 110-001_BaseMountBottom_floor.scad)
    120-001 Base Long Hardware/Models/100-Base/120-001_BaseLong.scad (with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
